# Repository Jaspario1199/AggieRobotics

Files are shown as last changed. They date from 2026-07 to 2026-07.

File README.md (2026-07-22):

# VEX Tri-Ball Belt Accelerator 🎯

A single VEX mechanism that **pushes, launches, pulls, and holds** a tri-ball —
a **belt accelerator** ("belt railgun"). The ball runs down a barrel gripped
between two motor-driven **conveyor belts** on its left and right (the "rails"),
with **top + bottom decks** containing it and forming the floor it rides on. Like
a railgun it accelerates the ball *along* the barrel — but the rails are traction
belts, and belt **surface speed** is the exit speed. One drive replaces an intake
**and** a puncher **and** a pusher: fewer subsystems, less weight, faster cycles.

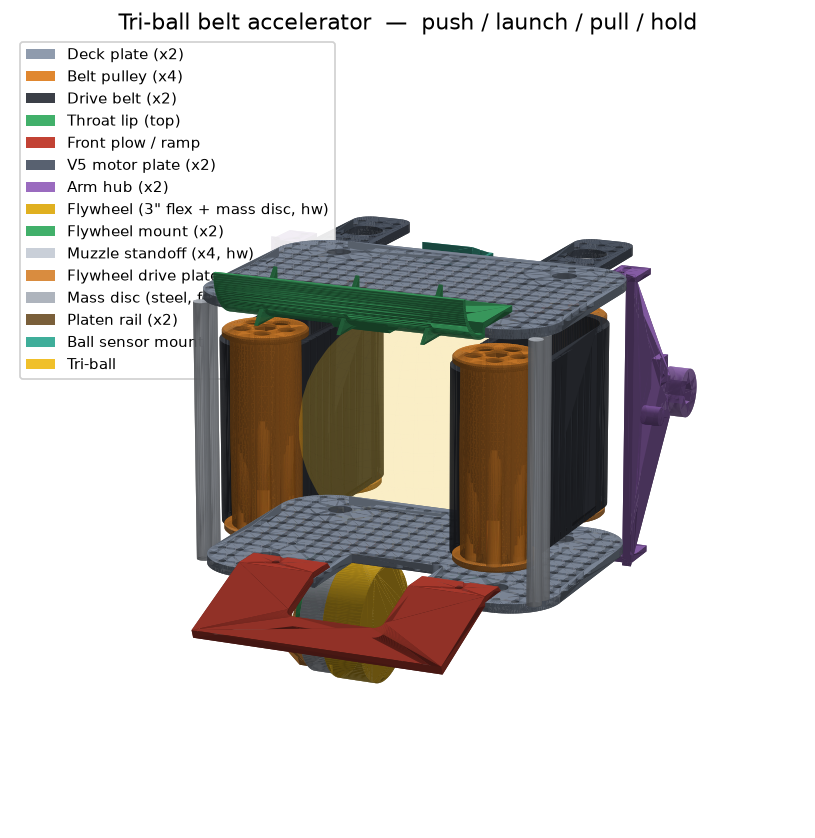
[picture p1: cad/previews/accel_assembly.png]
Tri-ball belt accelerator


## The four modes

| Mode | The belts… | …and the ball |
|---|---|---|
| **PULL** (intake) | run inward, **slow** | friction draws the tri-ball into the barrel |
| **HOLD** (control) | **stopped** | pinched between the belts (compression grip) |
| **LAUNCH** | run outward, **fast** | spun up to belt speed and fired out the muzzle |
| **PUSH** | **off** | drive forward — the front plow shoves it through a contested zone |

Because exit speed ≈ belt surface speed, you set a belt *speed* (not a launch
impulse) and the barrel length does the accelerating — so near/far shots are
repeatable.

## Design basis (first principles)

Sized from four relations, all parametric in [`cad/params.py`](cad/params.py):

| Quantity | Relation | Set by |
|---|---|---|
| Exit speed (no slip) | `v_exit ≈ v_belt = (RPM/60)·π·PULLEY_PITCH_DIA` | pulley Ø + motor RPM (gear-up) |
| Grip (no slip) | `μ·N ≥ m_ball·a` | `BALL_COMPRESSION` (normal force) |
| Channel gap | `BELT_GAP = TRIBALL_DIA − 2·BALL_COMPRESSION` | ball size + squeeze |
| Barrel length | accel distance to reach `v_belt` | `BARREL_LEN` |

Pick `PULLEY_PITCH_DIA` and motor RPM for the exit speed you want,
`BALL_COMPRESSION` for enough grip that the ball doesn't slip, and `BARREL_LEN`
long enough that the ball leaves at (near) belt speed. The side **belts squeeze**
the ball (`BELT_GAP < TRIBALL_DIA`) for grip, while the **top + bottom decks** sit
a hair wider than it (`2·SIDE_INNER_HALF > TRIBALL_DIA`) so it's captured but not
crushed and can't pop out top or bottom.

## Parts

Every part is a **parametric CadQuery script** that exports genuine **STEP**
(Fusion 360 / SolidWorks / FreeCAD / Onshape) and **STL** (ready to slice). The
generated files are committed, so you can open/print without installing anything.

| Part | What it is | Print | Material |
|---|---|---|---|
| [`belt_pulley`](cad/parts/belt_pulley.py) | Flanged traction pulley, ½" hex bore, lightened | ×4 | PLA/PETG |
| [`drive_belt`](cad/parts/drive_belt.py) | The traction loop the ball rides on — 6 mm thick so the 4 mm squeeze stays inside the belt (rigid ball) | ×2 | TPU 95A (printed — VEXU-legal fabricated part) |
| [`accel_plate`](cad/parts/accel_plate.py) | Grid-perforated deck (top + bottom); 4 vertical pulley bores (rear = tension slots); **flip-symmetric** | ×2 | PLA/PETG |
| [`throat_lip`](cad/parts/throat_lip.py) | Flared TOP mouth guide — bolts to the deck grid, zero aperture intrusion | ×1 | PLA/PETG |
| [`front_plow`](cad/parts/front_plow.py) | Bottom ramp + push blade + bottom mouth guide in one part (chamfered — no step in the ball path) | ×1 | PLA/PETG |
| [`motor_plate`](cad/parts/motor_plate.py) | V5 Smart Motor mount, geared up to a drive-pulley shaft (1.5" centre distance) | ×2 | PLA/PETG |

## Built to the VEX system

- **½" high-strength hex** bores on every pulley (`VEX_HEX_AF`); lock them on with
  shaft collars or the set-screw access hole.
- The **0.5" (12.7 mm) hole grid** fills each deck, so bearing flats, the throat
  lips, the plow, the V5 motors, and the drivetrain C-channel all bolt anywhere.
  The **rear pulley bores are tension slots** — slide the idlers back to tension
  each belt. Holes are **#8-32** clearance (`VEX_HOLE`).
- Sized for the VEX Over-Under **tri-ball** via `TRIBALL_DIA`. Tune
  `PULLEY_PITCH_DIA`, `BARREL_LEN`, `BELT_WIDTH`, `BALL_COMPRESSION`, and
  `SIDE_INNER_HALF` and re-run the export to fit a different element.

> The printed parts are the *custom* geometry (decks, pulleys, throat lips, plow).
> The motors, ½" hex shafts, bearing flats, gears, shaft collars, and the belts
> themselves are stock VEX / COTS — don't print those (print the belts in TPU
> only if you can't source a loop).

## Assembly

1. Snap a VEX **bearing flat** over each of the four pulley bores in each deck
   (front pair fixed; rear pair in the **tension slots**).
2. Stand a **belt pulley** on a **vertical ½" hex shaft** at each corner of the
   barrel — a front + rear pair on the left, a front + rear pair on the right —
   running between the top and bottom decks. Lock with shaft collars / set screws.
3. Loop a **drive belt** around each side's pulley pair (one belt left, one right);
   slide the rear idlers back in their slots to tension.
4. Bolt a **motor plate** on for each belt and gear the **V5 motor** up to that
   side's rear drive pulley (e.g. 12T→36T) for launch belt speed.
5. Bolt the two **throat lips** across the muzzle grid holes — one top, one bottom —
   to flare the mouth.
6. Bolt the **front plow** across the muzzle-floor grid holes — it also ties the two
   decks into a rigid frame.
7. Bolt the whole frame to your drivetrain C-channel through the grid.

## Regenerate the CAD

Edit [`cad/params.py`](cad/params.py), then:

```bash
pip install -r requirements.txt
python -m cad.export_all      # writes cad/{step,stl,previews}
```

## Print settings

- **Structural parts** (decks, pulleys, throat lips, plow): **PETG**, 0.2 mm
  layers, **4 walls**, **40–50 % infill** — these take load and impact.
- **Belts** (only if you can't source a loop): **TPU 95A**, so they flex around
  the pulleys.
- Most parts print support-free in the orientation described in each script's
  docstring. The throat lips overhang mildly — a couple of supports or a
  split-print are fine.

## Layout

```
cad/
  params.py         # ← edit YOUR dimensions here (ball size, belt/pulley sizing)
  parts/*.py        # one parametric script per part
  export_all.py     # regenerate everything + the assembly preview
  lib.py            # STEP/STL export + PNG preview helper
  vexlib.py         # 1/2" hex bore + 0.5" VEX hole-grid helpers
  step/  stl/  previews/   # generated output (committed)
```

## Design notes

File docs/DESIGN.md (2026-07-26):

# VEXU Over Under Robot — Design Document (working draft)

> **Process note.** No CAD until this document has been critiqued and iterated to
> "no holes." This is the single source of truth for *what every part is, why it
> exists, how it interacts with everything else, and how it is fastened.* Sections
> tagged **[RULES — pending]** are being grounded against the official VEXU Over
> Under manual (research in progress) and will be filled with cited numbers before
> we lock v1.

---

## 0. Locked decisions (from the user)

| # | Decision | Choice | Why it matters downstream |
|---|---|---|---|
| D1 | Drivetrain | **X-drive** (4 omni @ 45°) | Sets corner geometry, motor count (4), center-of-mass, and how the arm mass loads the base. |
| D2 | Starting envelope | **~15 in cube** (VEXU small-robot class; exact limit pending) | Everything must nest inside this at match start; the arm expands *after* start. |
| D3 | Actuation | **Hybrid** — motors for drive + belts, pneumatics for arm deploy/latch | Trades motor budget for air; sets solenoid/reservoir count. |
| D4 | Arm | **Linear slide + pivot** (telescoping extend, then fold to the back) | Two clean DOF; defines the shoulder joint, the slide, and the folded/deployed poses. |

---

## 1. Purpose & the core idea

Rebuild (and improve) a VEXU Over Under robot whose entire manipulator is **one
belt accelerator** (the "belt railgun" in this repo) mounted on a **fold-out
arm**, on a **holonomic X-drive** base.

The one manipulator does four things (see the mechanism README):

- **PULL** (intake) — belts run inward, draw the tri-ball into the barrel.
- **HOLD** — belts stop, ball pinched between them (ball control while driving).
- **PUSH** — belts off, drive forward, the plow shoves the ball.
- **LAUNCH** — belts spin up, ball fired out at belt surface speed.

**The dual-position trick.** The belt barrel is open at both ends and the belts
are reversible, so a *single* working mouth can both intake and launch. The arm
gives that mouth two useful home positions:

- **Deployed (extended forward):** the arm slides + swings the belt head out the
  **front** of the robot, mouth facing forward — intake off the field, or launch
  forward.
- **Folded (resting on the back):** the arm folds ~180° so the belt head lies on
  the rear deck with its mouth now facing **rearward** — intake/launch off the
  *back* of the robot without deploying the arm.

So the robot can work off either end depending on what the match wants, and the
**folded pose is also the legal start configuration** (compact, inside the cube);
**deploying = the post-start expansion** the rules allow.

---

## 2. Requirements

### 2.1 Rules/legality (VEXU / VURC 2023–24 Over Under)
Grounded against the VRC Over Under Game Manual v4.0 + VEX U appendix and the
VURC Q&A. Numbers are high-confidence unless flagged **(verify)**; the five
flagged items in §11-H9 must be checked against the manual PDF before the build.

- **R1 Two robots/team, two size classes.** Start cubes are **24×24×24 in** and
  **15×15×15 in**. *We are building the **15″ robot.*** It must start fully inside
  the 15″ cube and pass inspection there.
- **R2 Expansion after start (corrected — good news).** The **15″ robot is governed
  by standard SG2/SG3 → it may expand horizontally to 36 in**; only the *start* is
  the 15″ cube. The **24 in** cap (VUG2) applies to the team's *other* (24″) robot,
  not this one. → The arm's ~20.5″ deployed footprint is legal with large margin;
  reach is not the binding constraint (packaging/tipping are).
- **R3 Motors: no count cap in VEXU** (VRC's 88 W cap is removed). BUT VEXos
  drops the per-motor current limit once **>8 motors** are connected. → **Hold the
  total to ≤ 8 V5 motors** so each keeps full current (matters for launch power).
- **R4 Pneumatics (corrected):** **VEX pneumatics only**, **≤2 reservoirs**,
  **100 psi max**, VEX solenoids. (Not "less restricted" — the 2-reservoir limit
  binds.) **Air budget matters:** a 200 mL reservoir ≈ 15–25 double-acting actuations
  → don't cycle the slide every intake or it runs dry; compute the budget or move the
  slide to the spare motor.
- **R5 Parts (corrected to VEX U appendix, not VRC):** **3D-printed + custom-fabricated
  parts from the raw-material list are legal and unlimited** — **polyurethane is on the
  list, so TPU belts are legal as a fabricated part** (not "because COTS belts are
  banned"). **COTS bearings + linear slides/bearings are legal** (ruled "fasteners,"
  Q&A #1208). **COTS gears are NOT legal** (VUR4 — must be VEX or fabricated). **Only
  V5 Smart Motors** may actuate (no other motors/servos). **1 V5 Brain + 1 radio** per
  robot; **1 extra battery allowed for sensors/processing only** (not motors/solenoids).
  → Keep gears + motors + wheels VEX; the linear slide *may* be COTS but keeping it VEX
  is the safe call; print structure/pulleys/plates + TPU belts freely.
- **R6 No robot weight limit.** (Still keep mass sane for tipping/agility.)
- **R7 Two-robot team.** VEX U fields **two robots (24″ + 15″)**; the standard split is
  **big robot elevates, small robot scores.** *This* is the 15″ scorer → deferring hang
  (H11) is justified **iff** the 24″ partner elevates. Elevation scores **20/15/10/5**
  (confirmed); measured under the robot's lowest point (bar height: verify Appendix A).

**Field/scoring targets for the launcher (designer-usable):**
- Field **12 ft × 12 ft**; central **Barrier** ≈ **2.9 in** tall PVC — you launch
  *over* it. Each half ~72 in deep.
- **Two netted goals**, lowest opening ≈ **5.78 in** above the tiles; a triball
  scores when **≥2 of its 3 points are inside** = **5 pts** (offensive zone = 2).
- Launching over the barrier is **legal and mainstream**. Typical cross-barrier
  shot ≈ **4–8 ft** horizontal clearing a ~3 in barrier → **modest launch energy**
  (this shrinks the belt head we need). Never launch elements *out of* the field.

### 2.2 Functional
- F1 Intake a tri-ball off the floor (front, deployed).
- F2 Intake a tri-ball off the floor (rear, folded) — the "resting on the back" mode.
- F3 Hold a ball securely while driving holonomically (no ejection on hard turns).
- F4 Launch a ball across the field into the far goal (repeatable near/far).
- F5 Push a ball through a contested zone (belts off, plow engaged).
- F6 Deploy/retract the arm reliably and hold either pose under drive loads.
- F7 Drive omnidirectionally (translate + rotate simultaneously).

### 2.3 Mechanical / quality
- M1 Fit the start envelope with margin (target ≥ 0.5 in on each axis).
- M2 Center of mass low and centered enough that the deployed arm doesn't tip it.
- M3 Every load path resolved into metal fasteners into metal or heat-set inserts;
  no printed part carries a thread that sees repeated high load.
- M4 Field-serviceable: swap a belt, motor, or the whole arm head without a teardown.
- M5 Wire/air routing that survives the arm's full range of motion (no pinch/stretch).

---

## 3. System architecture

Six subsystems. Each has its own spec below; §7 is the interaction matrix and §8
the fastening scheme.

```
                         ┌─────────────────────────────┐
                         │  S6 Power & Electronics       │
                         │  (V5 brain, battery, radio)   │
                         └──────────────┬────────────────┘
             commands / power           │
        ┌───────────────┬───────────────┼───────────────┬──────────────┐
        ▼               ▼               ▼               ▼              ▼
  ┌───────────┐  ┌────────────┐  ┌────────────┐  ┌────────────┐ ┌────────────┐
  │ S2 X-drive │  │ S3 Belt    │  │ S4 Arm     │  │ S5 Pneu-   │ │ S1 Chassis │
  │ (4 motors) │  │ head       │  │ deploy     │  │ matics     │ │ / structure│
  │            │  │ (2 motors) │  │ (slide+piv)│  │ (air)      │ │ (frame)    │
  └─────┬──────┘  └─────┬──────┘  └─────┬──────┘  └─────┬──────┘ └─────┬──────┘
        │ reacts thrust  │ carries ball  │ moves head    │ actuates     │ carries
        └────────────────┴───────┬───────┴──────┬────────┘   slide/latch │ everything
                                  ▼              ▼                        ▼
                          the tri-ball    the field                 the cube envelope
```

- **S1 Chassis / structure** — the frame everything bolts to; two decks.
- **S2 X-drive** — 4 omni wheels @45°, 4 V5 motors; holonomic base.
- **S3 Belt head** — the belt accelerator (this repo's parts), 2 belt motors.
- **S4 Arm deploy** — shoulder pivot + linear slide that carry S3 between poses.
- **S5 Pneumatics** — reservoir(s), solenoids, cylinders for slide/latch.
- **S6 Power & electronics** — V5 brain, battery, radio, wiring, air valves.

---

## 4. Packaging & coordinate strategy

**World frame (robot):** +X = right, +Y = forward, +Z = up. Origin at the base
center on the floor plane.

**Two decks:**
- **Lower deck (drive deck):** X-drive motors + wheels, V5 battery, brain, and the
  air reservoir — the heavy stuff, low, for a low CoM.
- **Upper deck (arm deck):** the shoulder pivot, the linear slide rails, and the
  folded belt head resting surface. The belt head sits *here* when folded.

**Start (folded) config → fits the cube.** Belt head folded flat on the upper
deck, mouth facing rear, arm slide retracted, pivot latched. This is the ≤15″
start box.

**Deployed config → the legal expansion.** Slide extends forward, pivot swings the
head down/out to intake height at the front. The head clears the front drive
wheels because the X-drive corners are chamfered inward (§S2).

**The central packaging tension (must be solved before CAD):** the belt head is
inherently ~tri-ball-sized (the barrel wraps a ~7″ ball). A head that big folded
on a 15″ deck plus a 15″ X-drive base plus electronics is tight. Candidate
resolutions, to be decided in §11:
- (a) **Compact the head** to a *single* belt-gap barrel just long enough to grip
  the ball over ~1 wrap (shorten `BARREL_LEN`, drop to the minimum pulley count),
  accepting lower launch energy for size.
- (b) **Cantilever the head off the back** in the folded pose so it overhangs the
  rear bumper *within* the expansion allowance rather than the start cube — i.e.
  the head only has to be inside the cube if we call folded the "start," so we may
  instead start with the head nested lower and deploy both directions.
- (c) **Split decks vertically** — head folds into the volume *above* the drive
  motors, using full cube height (Z) rather than deck area (XY).

---

## 5. Subsystem specs

### S1 — Chassis / structure
**Purpose:** rigid frame that (a) locates the 4 X-drive corners, (b) carries the
two decks, (c) provides the shoulder-pivot mounts and slide-rail mounts, (d) takes
launch reaction and drive thrust into the wheels without racking.

**Build:** VEX aluminum C-channel perimeter (square), corner gussets, standoffs
between decks. Custom 3D-printed brackets only where they *locate* parts, not where
they carry the primary launch load (that goes through C-channel + steel screws).

**Key interfaces:**
- 4× corner motor/wheel modules (S2) bolt to the lower-deck corners at 45°.
- Shoulder-pivot bearing blocks (S4) bolt to the upper deck, rear edge.
- Slide rails (S4) bolt along the upper deck.
- Battery/brain/reservoir trays (S6/S5) strap to the lower deck.

**Fastening:** C-channel joined with 8-32 screws + nylocks through the 0.5″ grid;
printed brackets use heat-set inserts *only* for light locating loads; primary
load joints are metal-to-metal.

### S2 — X-drive (holonomic)
**Purpose:** omnidirectional translation + rotation; also *reacts the launch
recoil* and any push loads.

**Build:** 4× VEX 4″ omni wheels at the four corners, each wheel's roller axis at
45° to the frame, each driven by 1× V5 Smart Motor through a spur pair (ratio TBD
for a speed/torque target; start ~ direct or 1:1.6 for speed). Wheels ride on ½″
hex axles in bearing flats.

**Why X-drive (recap):** compact center (leaves the middle free for the arm mass
and battery), true holonomic, and the 45° wheels keep the corners — where the
front wheels would otherwise block the deployed head — clear.

**Motors:** 4 (one per corner). **[RULES — pending]** confirm this fits the budget
alongside S3's belt motors and S4.

**Interactions:** must *hold position* during launch (recoil pushes the base
backward); driver or code applies a brief brace (all wheels resist) at launch, or
we launch only while translating to cancel recoil. Flagged as a control item (§6).

### S3 — Belt head (the manipulator)
**Purpose:** the four-mode manipulator (pull/hold/push/launch). This is the belt
accelerator already modeled in this repo (`cad/parts/*`): 4 `belt_pulley`, 2
`drive_belt`, 2 `accel_plate` decks, 2 `throat_lip`, 1 `front_plow`.

**Tri-ball reality (corrects the mechanism's current sizing):** the ball is a
**three-lobed shape ≈ 6.18 in tip-to-tip**, body ≈ 4–4.5 in across, ≈ **138 g**,
hollow plastic — *not* a 178 mm sphere. Two consequences:
- The **throat opening** must admit the ~6.18 in tip dimension in any orientation
  (the ball is irregular, so intake orientation matters), while the **belts grip
  the ~4–4.5 in body**. So: wide throat, narrower belt gap. `TRIBALL_DIA` in
  `params.py` becomes the *tip* size for the throat; a new `BALL_BODY` (~110 mm)
  sets `BELT_GAP`. → **[H10]**.
- Everything shrinks vs. the current model — good for §4 packaging (H1).

**Adaptation for the arm:**
- `BARREL_LEN`, `BELT_WIDTH`, and pulley Ø are the levers to size the head to the
  corrected ball and the folded envelope (§4, §11).
- **Belts are 3D-printed TPU** (legal custom part per R5) — not a COTS belt. Tread
  wraps the ~4–4.5 in body for grip.
- **Reversible + dual-end:** belts driven by 2 V5 motors (one per side) for
  independent spin control and launch power; the barrel's single mouth intakes or
  launches by belt direction/speed, and the fold reorients that mouth front↔rear.
- **Launch energy is modest** (R2 target ~4–8 ft over a ~3 in barrier, 138 g ball),
  so the head need not be large — belt surface speed + a good exit angle dominate.
- Mounts to the arm's moving carriage (S4) via the belt-head decks' grid holes.

**Motors:** 2 (belt L, belt R). Could be reduced to 1 with a cross-linkage if the
motor budget is tight — noted as a trade in §11.

**Interactions:** hands the ball to "the field" on launch; receives it from the
floor on intake; its mass is the biggest thing the arm (S4) has to move and the
base (S2) has to keep from tipping.

### S4 — Arm deploy (linear slide + pivot)
**Purpose:** carry the belt head (S3) between **folded** (rear deck, mouth rear)
and **deployed** (front, mouth forward, at intake height), and hold either pose
under load.

**Two DOF:**
1. **Shoulder pivot** — a hinge at the rear-top of the upper deck. Swings the arm
   ~180° from lying-on-the-back to pointing-forward-down. **Actuation candidate:**
   a V5 motor through a high-reduction gearbox (holds position, precise angle) —
   *or* pneumatic via a linkage if we can hit the throw (decision in §11; motor
   is the current lean because 180° under a heavy head wants controlled, holdable
   motion).
2. **Linear slide** — a telescoping rail on the arm that extends the head forward
   for reach when deployed. **Actuation:** pneumatic cylinder (fast, self-holds at
   both stroke ends), matching D3 (pneumatics for deploy).

**Latch:** a pneumatic (or passive over-center) latch holds the **folded** pose for
the start and during hard driving so the head can't flop; released to deploy.

**Interactions:** the pivot axis, slide stroke, and folded rest surface are the
geometry that S1 must provide and that S3's size must fit; the air lines and the 2
belt-motor cables must survive the full travel (S5/S6 routing).

### S5 — Pneumatics
**Purpose:** actuate the linear slide (extend/retract) and the fold latch; possibly
a launch-hood/angle flip. **[RULES — pending]** confirm reservoir/cylinder count.

**Build (candidate):** 1–2 air reservoirs on the lower deck, a regulator, and
2–3 double-acting cylinders (slide, latch, optional hood) driven by V5 pneumatic
solenoid valves off the brain's 3-wire ports.

**Interactions:** valves commanded by S6; cylinders act on S4; reservoir mass sits
low in S1 for CoM.

### S6 — Power & electronics
**Purpose:** power and command everything.
**Build:** 1× V5 Brain, 1× V5 Battery, 1× V5 Radio + controller, motor cables,
3-wire leads to pneumatic solenoids, and (optional) sensors: an optical/distance
sensor at the mouth (ball present?), an IMU for field-oriented holonomic drive, and
motor encoders (built into V5) for belt-speed = launch-speed closed loop.
**Interactions:** every subsystem; wire routing across the arm hinge is a named
risk (M5). **[RULES — pending]** total motor count must fit the VEXU limit.

---

## 6. Control strategy (per mode)

| Mode | Drive (S2) | Belts (S3) | Arm (S4) | Pneu (S5) | Notes |
|---|---|---|---|---|---|
| Drive/seek | holonomic | off or HOLD | folded or deployed | latched | field-oriented via IMU |
| Intake front | creep fwd | PULL (inward, slow) | deployed, mouth fwd | slide out | ball sensor confirms capture → HOLD |
| Intake rear | creep back | PULL | folded, mouth rear | latched | no deploy needed |
| Hold + travel | holonomic | HOLD (stall/creep) | either | — | belts lightly grip; no launch energy |
| Push | drive into ball | off | deployed low | slide out | plow engaged |
| Launch | brace/translate to cancel recoil | spin up to target belt speed | pose set for angle | hood set | encoder closes speed loop for range |

**Recoil:** launching a ~60 g ball at speed imparts a recoil impulse; the X-drive
holds/opposes it (all four wheels brace), or we launch while creeping to cancel —
a control-level item, but it validates choosing a holonomic base that can hold
station.

---

## 7. Interaction matrix (who touches whom, and how)

| ↓ acts on → | S1 Chassis | S2 Drive | S3 Belt head | S4 Arm | S5 Pneu | S6 Elec |
|---|---|---|---|---|---|---|
| **S1 Chassis** | — | locates 4 corners; takes thrust | provides folded rest surface | provides pivot + rail mounts | holds reservoir tray | holds brain/battery trays |
| **S2 Drive** | thrust/recoil into frame | — | keeps base under the ball | keeps base stable while arm moves | — | draws power/PWM |
| **S3 Belt head** | mass on upper deck | ball control aids pushing | — | is the payload the arm carries | — | 2 motor cables |
| **S4 Arm** | loads pivot/rails | shifts CoM when deployed | positions + orients the mouth | — | driven by slide cylinder + latch | motor cable + encoder |
| **S5 Pneu** | reservoir mass | — | — | extends slide, throws latch | — | solenoids on 3-wire ports |
| **S6 Elec** | tray loads | commands drive | commands belts + reads ball sensor | commands pivot + reads angle | commands valves | — |

*(Each non-empty cell is a real interface that must have a defined mount, load
path, and — where it moves — a routing plan. Cells that move relative to each other
across the hinge: S3↔S6 cables and S4↔S5 air lines — flagged M5.)*

---

## 8. Fastening scheme (global rules)

1. **Primary structure (frame, decks, motor mounts, shoulder blocks):** VEX metal
   C-channel/plate, joined with **8-32 screws + nylock nuts** through the 0.5″ grid.
   No printed part in a primary load path.
2. **Shafts:** ½″ hex in VEX bearing flats; wheels/pulleys/gears retained with
   **shaft collars + set screws**; hex captures torque.
3. **Printed parts (belt head decks, pulleys, throat lips, plow, brackets):**
   bolt to metal with 8-32 clearance holes + nuts; where a screw must thread into
   plastic, use a **heat-set brass insert**, never a bare tapped hole under load.
4. **Belt-head to arm carriage:** the two accel-plate decks bolt to the carriage
   through their existing 0.5″ grid, straddling the pulley bores for a stiff joint.
5. **Pivot joint:** hardened ½″ or ¾″ shaft in dual bearing blocks (both sides),
   never a single-shear printed pivot.
6. **Air/electrical:** service loops at the hinge; strain-relief clamps on both the
   fixed and moving sides so nothing pulls on a connector.

---

## 9. Mass / CG budget (rough, to refine)

| Group | Est. mass | Location | CoM effect |
|---|---|---|---|
| X-drive (motors+wheels+frame) | heavy | low, corners | anchors CoM low/centered |
| Battery + brain + reservoir | heavy | low deck, centered | low CoM |
| Belt head + 2 motors | heavy | upper/rear (folded) or front (deployed) | **the swing risk** |
| Arm slide + pivot gearbox | medium | upper rear | rear-biases CoM |

**The tipping check (must pass in §10 iteration):** with the arm fully deployed
forward + a ball at the mouth, the CoM must stay inside the front wheelbase with
margin. Levers: keep battery/reservoir low and rearward to counterbalance; limit
slide extension; widen the effective front track via the 45° wheel geometry.

---

## 10. BOM (skeleton — quantities/motors finalize after [RULES])

| Subsys | Item | Qty | Purpose |
|---|---|-----|---|
| S1 | VEX aluminum C-channel (various) | TBD | frame perimeter + decks |
| S1 | Corner gussets / plates | TBD | rack-resist the frame |
| S1 | Standoffs (deck spacers) | TBD | separate the two decks |
| S2 | VEX 4″ omni wheel | 4 | X-drive |
| S2 | V5 Smart Motor (11W) | 4 | drive |
| S2 | ½″ hex axle + bearing flats + collars | 4 sets | wheel mounts |
| S2 | Spur gear pair | 4 | drive ratio |
| S3 | `belt_pulley` (printed) | 4 | belts ride on these |
| S3 | `drive_belt` (**3D-printed TPU** — legal custom part) | 2 | grip + accelerate the ball |
| S3 | `accel_plate` deck (printed) | 2 | barrel walls / pulley mounts |
| S3 | `throat_lip` (printed) | 2 | flared mouth |
| S3 | `front_plow` (printed) | 1 | push mode + cross-brace |
| S3 | V5 Smart Motor | 2 | belt drive (or 1 + cross-link) |
| S3 | ½″ hex shafts + bearings + collars | 4 | pulley shafts |
| S4 | Linear slide rail + carriage | 1 | extend the head |
| S4 | Pneumatic cylinder (slide) | 1 | extend/retract |
| S4 | Shoulder pivot shaft + bearing blocks | 1 set | fold DOF |
| S4 | V5 Smart Motor + gearbox (pivot) | 1 | fold actuation (candidate) |
| S4 | Latch (pneumatic or over-center) | 1 | hold folded |
| S5 | Air reservoir | 1–2 | pneumatic supply |
| S5 | Solenoid valve | 2–3 | slide/latch/hood |
| S5 | Regulator + tubing + fittings | 1 set | plumbing |
| S6 | V5 Brain | 1 | controller |
| S6 | V5 Battery | 1 | power |
| S6 | V5 Radio + Controller | 1 | comms |
| S6 | Optical/distance sensor | 1 | ball-present at mouth |
| S6 | IMU (or V5 built-in) | 1 | field-oriented drive |

**Motor tally:** 4 drive + 2 belt + 1 pivot = **7 V5 motors** (slide + latch are
pneumatic). VEXU has no motor cap, but we deliberately stay **≤8** so VEXos keeps
each motor at full current (launch power). 1 spare port; use it for an assist
roller, a 2nd pivot motor, or leave it. All motors + wheels + gears + bearings +
shafts are **VEX** (R5); pulleys/plates/lips/plow are **printed**, belts **TPU**.

---

## 11. Open holes to close *before* CAD (the iteration list)

These are the "holes" we critique and drive to zero. Each must get a decided
answer written back into the sections above.

- **H1 Size reconciliation** *(the #1 hole; eased by H10)* — does the belt head fit
  folded in the 15″ cube with the X-drive + electronics? With the corrected smaller
  ball the head shrinks a lot; still must pick the packaging (§4 a/b/c) and prove
  the folded stack ≤ 15″ on all axes with ≥0.5″ margin, and the deployed footprint
  ≤ the R2 horizontal cap.
- **H2 Fold actuation** — motor vs pneumatic-linkage for the ~180° pivot; confirm it
  holds the head folded and deployed under drive/recoil. (Motor is the lean.)
- **H3 Motor budget** — *mostly resolved:* VEXU has no cap but we hold **≤8** to keep
  full current. Plan = 4 drive + 2 belt + 1 pivot = **7** (1 spare). Decide 1-vs-2
  belt motors only if we want the 8th for an assist roller or 2nd pivot motor.
- **H4 Recoil management** — quantify launch recoil (≈ m·Δv of a 138 g ball) vs base
  holding force; confirm the X-drive holds station, or launch-while-creeping.
- **H5 Tipping** — CoM/wheelbase check deployed + loaded (§9).
- **H6 Dual-end geometry** — verify the *same* mouth presents correctly both folded
  (rear) and deployed (front); define the two intake heights (front floor pickup;
  rear pickup height when folded). Throat must clear the 6.18″ tip in any orientation.
- **H7 Wire/air over the hinge** — define the service-loop routing (M5).
- **H8 Launch performance** — *targets now known:* clear a ~2.9″ barrier into a goal
  whose opening is ~5.78″ up, ~4–8 ft away, 138 g ball. Solve exit speed → belt
  surface speed = `(RPM/60)·π·PULLEY_PITCH_DIA` → motor RPM + gear-up; set a launch
  angle (hood). Modest energy → confirms a small head is enough.
- **H9 Rules legality** — *filled (§2.1).* Residual items to verify against the
  manual PDF: (1) 15″-robot horizontal expansion cap; (2) elevation-bar height +
  point values; (3) exact VUR rule IDs; (4) triball weight/secondary dims; (5) VEXU
  reservoir-count nuance / 2nd brain-battery allowance.
- **H10 Ball re-size** — update `params.py`: `TRIBALL_DIA` → ~6.18″ *tip* (throat),
  add `BALL_BODY` ~110 mm → `BELT_GAP`; re-derive head size. Feeds H1/H6/H8.
- **H11 Endgame hang (optional / stretch)** — elevation scores 20/15/10/5. Could the
  folding arm double as a hook to hang on the Elevation Bar? Big value if cheap;
  out of core scope for v1 but worth a hook geometry check before we finalize the arm.

---

## 13. Resolved design — closing H1–H11 (v0.3)

Concrete decisions + numbers that supersede the placeholders above. Units mixed
(VEX is imperial; mechanism is metric) but each value notes both where it matters.
Masses/dims marked ≈ are engineering estimates to confirm in CAD.

### 13.0 Tri-ball working numbers (H10 — closed)
- Tip-to-tip **157 mm (6.18″)** → sets throat + tip-clearance.
- Body across **≈110 mm (≈4.3″)** → sets the belt grip *(community-approx; verify)*.
- Mass **138 g**, **rigid hollow shell** → grip by **compliant TPU belts** (belts
  deform, ball doesn't). `params.py`: `TRIBALL_DIA`=157 (throat), new `BALL_BODY`=110.

### 13.1 Chassis (S1) — closed
- Footprint **368 × 368 mm (14.5″)** inside the 15″ cube (≈0.5″/side margin, M1).
- Drive deck height **≈100 mm (4″)**; upper/arm deck above it.
- VEX aluminum C-channel perimeter + corner gussets; steel 8-32 through the 0.5″ grid.

### 13.2 X-drive (S2) — closed
- 4× VEX **3.25″ omni** at 45° corners, **½″ hex** in bearing flats, **shaft-collar**
  retained. Each on **1× V5 motor, 600 RPM (blue) cartridge, ~1:1** → **≈8 ft/s** free.
- Holonomic control + **field-oriented via a V5 Inertial (IMU)**.
- **Recoil (H4 — closed):** launch impulse = m·v = 0.138 kg × 6 m/s ≈ **0.83 kg·m/s**;
  over a ~0.06 s contact ≈ **~14 N** peak. Wheel friction (robot ≈5 kg → ~25 N/wheel
  static) dwarfs it → base holds station; **no special recoil measure needed**, and
  code adds a 4-wheel brace at launch for repeatability.

### 13.3 Belt head (S3) — compact, closed (H1)
- `BELT_GAP` **≈100 mm** (grips the ≈110 mm body via TPU deform).
- Tip clearance (deck spacing across the other axis) **≈170 mm** so the 157 mm tips
  clear as the ball tumbles in.
- `BARREL_LEN` **≈90 mm**, `BELT_WIDTH` **≈90 mm**, `PULLEY_PITCH_DIA` **50 mm**.
- Throat lips flare the mouth to **≈160 mm** to swallow the tip in any orientation;
  the throat **cams the ball into a repeatable lobe-leading pose** for consistent
  launch (H6 detail; confirm against real ball CAD).
- **Head envelope ≈ 180 × 165 × 150 mm (≈7 × 6.5 × 6″)** — about half the robot.
- **2× V5 belt motors** geared **≈3.75:1** (600 RPM → ~2250 RPM at the 50 mm pulley).
- **Launch (H8 — closed):** belt surface speed v=(RPM/60)·π·D = (2250/60)·π·0.05 ≈
  **5.9 m/s**. Projectile range R=v²·sin2θ/g: at 45°, v=4.9 m/s→**2.4 m (8 ft)**;
  v=3.5→1.25 m (near). So **~3.5–6 m/s covers the whole ~4–8 ft window**; clears the
  74 mm barrier and reaches the ~147 mm goal opening. Speed set by encoder-closed
  belt RPM; a **launch hood sets ~40–45°**. Modest energy → the compact head suffices.

### 13.4 Arm (S4) — closed (H1/H2/H6)
- **Fold plane is vertical (fore-aft).** The shoulder pivot swings the head between
  **front-floor** (deployed intake/launch) and **rear working** (folded intake/launch
  off the back), passing over the top. ~**180°** throw.
- **Pivot = V5 motor + ≈7:1 reduction** (H2 — closed). Hold torque worst case
  (head ≈1.5 kg at ≈0.2 m, horizontal) = m·g·r ≈ **2.9 N·m**; motor+7:1 gives
  ample margin and 180° in ~1.5 s; **active braking holds deployed**, and a
  **pneumatic latch** holds folded (start + hard driving).
- **Slide = VEX linear rail + pneumatic cylinder, stroke ≈100 mm (4″)** for front reach.
- **Deployed footprint:** base 14.5″ + reach ≈6″ ≈ **20.5″ < 24″** expansion target (R2).
- **Poses / intake heights (H6 — closed):**
  - *Start/folded:* head at rear, mouth angled **down-rear ~30–45°** to work off the
    floor behind; slide retracted; latched. Stack height ≈ **280 mm (11″) < 15″** (M1).
  - *Deployed-front:* mouth at floor (**0–50 mm**), slide out.

### 13.5 Pneumatics (S5) — closed
- **1 air reservoir**, regulator at **~60–80 psi** (100 psi max, R4), on the low deck.
- **2 double-acting cylinders:** slide (≈100 mm stroke) + fold latch — each on a V5
  **3-wire solenoid**. (Reserve capacity for an optional hood cylinder.)

### 13.6 Power/electronics (S6) — closed
- **7 V5 motors** (4 drive, 2 belt, 1 pivot) — ≤8 for full current (R3). **1 spare port.**
- V5 Brain, Battery, Radio + Controller; **Inertial sensor** (field-oriented drive);
  **1 distance/optical sensor** at the mouth (ball-present → auto HOLD); motor encoders
  close the belt-speed loop for launch range.
- **Routing (H7 — closed):** the 2 belt-motor cables + pivot encoder + the slide air
  line cross the shoulder **coaxially with the pivot axis** with a service loop,
  strain-relieved on both fixed and moving sides (M5). Reservoir/valves on the low deck.

### 13.7 Tipping (H5 — closed)
- Deployed + ball: head ≈1.5 kg at ≈0.25 m ahead of pivot → CoM shift ≈ 1.5·0.25/5.0
  ≈ **75 mm** forward; front half-wheelbase ≈ **184 mm** → **stable with ~2.4× margin**.
  Keep **battery + reservoir low and rear**; cap slide extension. Confirm with CAD masses.

### 13.8 Endgame hang (H11 — decision)
- **Deferred to a v2 stretch,** *but* we **reserve the 8th motor port and add a hook
  boss** to the head so the arm can later hook the Elevation Bar (20 pts) without a
  redesign. Not on the v1 critical path.

### 13.9 Motor & pneumatic budget (final)
| Motor | Use | Cartridge / ratio |
|---|-----|---|
| ×4 | X-drive | 600 RPM, ~1:1 |
| ×2 | belts | 600 RPM, ~3.75:1 up |
| ×1 | arm pivot | ~7:1 down |
| (spare) | reserved (hang / assist) | — |

Pneumatics: 1 reservoir, 2 cylinders (slide, latch), 2 solenoids.

**All eleven holes H1–H11 now have a written resolution.** Remaining before CAD:
one adversarial critique pass to catch anything missed (§11 says "iterate to no
holes"), plus confirming the five flagged rule numbers (H9) against the manual PDF.

---

## 15. v1.0 — post-critique resolved design (supersedes §13)

Every §14 finding folded in. Launch-independent holes are closed with corrected
numbers; the two things that genuinely need a bench prototype are called out (§15.9)
rather than fake-closed. **Working launch baseline = flywheel-fed-by-belt** (my
recommendation; reversible — only §15.4 changes if we go catapult).

### 15.0 What survived, what changed
- **Belt keeps 3 of its 4 jobs — intake / hold / push / ball-control — unchanged.**
  It is no longer the launcher (both red-teams: wrong tool for a rigid irregular ball).
- **Launch is now a dedicated flywheel** the belt feeds. This is the only architectural
  change; everything else is a numbers/geometry fix.

### 15.1 Fold kinematics — fixed topology (closes C-B1/B4)
The rear-pivot + 100 mm slide was impossible. New scheme: **center-top pivot +
telescoping slide.**
- **Pivot at the robot center**, z ≈ 110 mm (top of drive deck), in **dual** bearing
  blocks (no single-shear). Driven by the pivot motor.
- **Short arm** (pivot → head carriage) + **slide** provides reach. The head folds into
  the **center-to-rear** deck span (≈190 mm — exactly the head length), mouth rearward,
  for the legal start. Deployed, the arm swings forward-down and the **slide extends** to
  put the mouth at the **front floor** and over the front edge (barrier reach).
- **Swing clearance:** head radius ≈190 mm about a center pivot → peak height ≈300 mm
  < 381 mm cube, and stays within ±190 mm horizontally. **Slide must retract before
  folding** (interlock, C-M12); the swept volume through 0–180° must clear the wheels/
  electronics.
- **Residual (legit CAD item):** exact link lengths + the 0/30/…/180° pose drawings are
  a **CAD swept-volume study** — the topology closes; the millimeters get set on the drawing.

### 15.2 Head — corrected envelope, mass, load path (closes C-B3/M2/M6)
- **Envelope ≈ 190 (L) × 210 (W) × 182 (H) mm**, mass **≈ 2.0 kg** (2× V5 ≈ 0.46 kg alone).
- **Metal structural spine** (VEX C-channel/plate) carries belt tension, the carriage
  joint, and the flywheel/pulley bearing loads; **printed plates become shrouds/guides,
  not primary structure** (obeys §8.1). Pulleys get **VEX/metal hubs or heat-set inserts**
  — no plastic hex bore under launch/intake torque reversal.

### 15.3 Belt intake (role unchanged, re-geared)
- Grips the ≈110 mm body; throat flares to swallow the 157 mm tip; **`BELT_WIDTH` → ~120 mm**
  (≥ body, fixes C-M14). Since the belt no longer launches, gear it for **intake speed
  (~1:1)**, not 3.75:1 — lower stress, no seam-ripple launch dependence (defuses C-M3).
- **1 belt motor** (cross-linked L/R) suffices for intake/hold → frees a port. A throat
  detent/hard stop holds the ball so belts needn't stall-hold (C-m5).

### 15.4 Flywheel launcher (new — closes C2-B1)
- **Dedicated flywheel at the muzzle** with **real metal flywheel mass** (VEX/fabricated) =
  the energy store the belt lacked. Driven by **1 V5 motor geared UP** to a rim speed of
  ~5–7 m/s; **encoder holds RPM**, flywheel inertia carries the shot (no torque-starve).
- **Belt feeds the ball into the flywheel nip; a compression hood** holds it against the
  wheel over a defined arc → more consistent than a single-tangent kick, and sets the
  **launch angle (~40–45°)**.
- **Rate ~1 shot/s** (re-spin); **mid-range** (~4–8 ft, over the 2.9″ barrier, into the
  net) — the far goal (>8 ft) is a stretch, accepted. **Trajectory = launch-from-height,
  and must clear/stay under the midfield Elevation Bar structure** (C2-B2) — a real
  CAD/sim check with field geometry, not the flat-ground formula.

### 15.5 Motor & pneumatic budget (final, ≤8)
| Motor | Use | Cartridge / ratio |
|---|-----|---|
| ×4 | X-drive | 600 RPM ~1:1 |
| ×1 | belt intake (cross-linked) | ~1:1 |
| ×1 | flywheel launch | up to ~5–7 m/s rim |
| ×1 | arm pivot | **100 RPM cartridge** ×~7 → ~14.7 N·m ≫ the ~5.6 N·m hold need (fixes C2-m2) |
| (spare) | 2nd flywheel or 2nd belt | — |
= **7 motors, 1 spare.** Pneumatics: **VEX, ≤2 reservoirs, 100 psi**; **compute the air
budget** — slide gets a mechanical hard-stop; **fold latch is passive over-center** (works
powered-off for inspection). If air budget is tight, motor the slide with the spare port.

### 15.6 Localization + controls (closes C2-M5)
- **2–3 dead-wheel tracking pods** for X/Y odometry (omni encoders slip) + IMU heading →
  field position for auton/skills aiming; a **goal-relative align routine** before launch.
- Ball-present distance sensor → auto-HOLD; launch only when not flooring the drive (peak-
  current, C2-m7). Recoil is a non-issue (~14 N ≪ ~49 N total friction).

### 15.7 Two-robot strategy (closes C2-M4 / R7)
This is the **15″ scorer**; the team's **24″ robot elevates**. Hang deferred here is now
*justified*, not hand-waved. (If we later want this bot to also hang, that's a v2 with the
spare port + a hook — not on the v1 path.)

### 15.8 Margins to re-verify in CAD (with real masses)
Start footprint incl. wheels/fasteners → target frame **≤360 mm (≈0.4″/side margin**, fixes
m1/C-M7); tipping with the ~2 kg head deployed (battery + reservoir low & rear); front-wheel-
gap clearance for the ~210 mm head mid-fold (C-M5).

### 15.9 The two things a prototype must close *before/at* CAD (honest)
Both red-teams agree these can't be closed on paper:
1. **Belt capture of the real rigid tri-ball** — does the throat actually orient/admit a
   157 mm irregular ball without jamming? Bench-test with the real (or printed) ball.
2. **Flywheel launch consistency** with the real ball — measure exit-speed/angle scatter.
→ Recommend a quick physical bench test (or a printed-ball proxy) to de-risk before
committing full CAD; or proceed to CAD with the compression-hood + detent mitigations
designed in and validate on the first print.

---

## 14. Critique round 1 — mechanical red-team (REOPENS "closed" holes)

An adversarial mechanical review re-did the §13 arithmetic and found several
closures don't hold. §13's "all holes closed" is **retracted** pending redesign.

**Blockers**
- **C-B1 Fold kinematics don't close.** Rear pivot + 100 mm slide can't reach the
  front floor *and* fold in-cube: pivot→mouth ≈ 518 mm horizontal, arm ≈ 430–530 mm;
  folding it rearward busts the 381 mm cube by ~250 mm or points it up. → **reopen H1/H6;**
  must publish real pivot (x,z), link lengths, slide stroke, and draw 0–180° poses.
  Likely needs a *central* pivot, longer slide, or a 2nd link.
- **C-B2 Rigid 3-lobe ball breaks belt-launch repeatability.** Belt-speed=exit-speed
  is sphere logic; lobe-apex contact → variable effective radius → non-repeatable
  speed/spin; 157 mm tip won't enter a 100 mm gap (jam risk); TPU must deform ~5 mm
  (> belt thickness). → **architecture question:** prototype on the real ball, or split
  intake (compliant flex-wheel) from launch (flywheel/catapult).
- **C-B3 Head undersized.** Real envelope ≈ **190×210×182 mm** (tip-clearance 170 +2 decks
  = 182; belt+pulley flanges → ~210 wide), not 180×165×150. Every downstream packaging
  number inherits this. → **reopen H1.**
- **C-B4 Rear floor intake can't be both in-cube and reach the floor.** Latched folded
  pose can't put the mouth at the rear floor without ~120 mm rear overhang (busts cube).
  → decide: rear intake is a post-start *deploy* (counts vs expansion cap), or drop it.

**Major**
- **C-M1** 90 mm `BARREL_LEN` < ball → no real acceleration distance (H1 fix broke H8).
- **C-M2** Printed PETG decks + plastic-hex pulleys are in the launch/cantilever load
  path — violates §8.1/M3. Need a metal structural spine + metal-hub pulleys.
- **C-M3** Printed TPU belt @2250 RPM: seam speed-ripple + fatigue = worst launch
  consistency, and R5 forces it. Consider **VEX flex wheels / tank tread** (VEX = legal)
  instead of a belt.
- **C-M4** Single linear slide = compliant cantilever holding ~2 kg → aim sag/creep.
  Need dual rails or a trussed pivot-only arm + a hard stop at the launch angle.
- **C-M5** Head (~210 wide) may not clear the gap between front drive modules mid-fold.
- **C-M6** Head mass ~1.8–2.0 kg (2× V5 = 460 g alone) → pivot hold ≈ 4.9 N·m, tipping
  ~1.8× not 2.4×.
- **C-M7** Cube margin ~0.25″/side excludes omni wheels + fasteners → may exceed 15″.

**Minor:** deployed pose needs a mechanical hard-stop not motor-hold; start latch must
be passive (inspection is powered-off); dynamic tipping unanalyzed; hood-vs-tilt launch
angle contradiction; double-articulation cabling fatigue; slide-retract-before-fold
interlock; deployed 20.5″ rides on the unverified 24″ cap; belt width 90 < body 110.

**Top 3 to fix:** (1) close fold kinematics with real geometry; (2) prototype belt grip
on the real rigid tri-ball before CAD — seriously weigh flex-wheel-intake + flywheel;
(3) reopen H1 with correct head dims + mass + wheel clearance.

### Critique round 2 — rules / controls / launch-physics red-team

**Blockers**
- **C2-B1 No energy store for launch.** 2× V5 @600 RPM geared 3.75:1 up → ~0.19 N·m at
  the pair of 50 mm pulleys, but the shot needs ~0.29 N·m — **motor stall torque is below
  the shot demand.** The energy must come from flywheel inertia the doc never sized;
  ~2 kg flywheel needed for <10% droop (impossible on a 15″ bot), ~0.4 kg → ~30% speed
  droop → range scatter; re-spin ≈ 0.7–1 s → ~1 shot/s. **The belt cannot be a
  repeatable launcher without becoming a flywheel shooter with real (metal) flywheel mass.**
- **C2-B2 Trajectory used flat-ground physics + ignored the field.** `R=v²sin2θ/g` assumes
  equal launch/land height; real shot is launch-from-height into a raised net. At 45°,
  5 m/s → **apex ≈ 24″** — and midfield has the **Elevation Bar structure** ("Over
  **Under**"); the arc must clear/stay under it. Belt-surface 5.9 vs range-calc 3.5–4.9 m/s
  implies unstated 15–40% slip. **Far goal (>8 ft) is unreachable** at this speed →
  mid-range only. Redo trajectory from height into real goal geometry + bar no-fly zone.

**Major**
- **C2-M1** Irregular ball → variable grip radius/release → exit **speed *and* angle**
  scatter at constant RPM; encoder loop can't fix geometry. (Confirms C-B2.)
- **C2-M2/M3 Rules re-framed** (now in R2/R4/R5/R7): 15″ expands to 36″; VEX pneumatics
  ≤2 reservoirs; TPU belts legal (fabricated); COTS bearings/slides legal, COTS gears not;
  only V5 motors; two-robot game. Air budget can run dry — compute or motor the slide.
- **C2-M4** Two-robot strategy undocumented → "defer hang" only valid if the 24″ partner
  elevates (now R7).
- **C2-M5** **No localization** → auton/skills aiming unsupported (IMU = heading only,
  omni odometry slips). Add dead-wheel tracking pods or a goal-relative align routine.

**Minor (verified):** start margin 0.25″/side not 0.5″ (m1); **pivot needs the 100 RPM
cartridge** — deployed r≈0.35 m, m≈1.6 kg → ~5.6 N·m, a 600-RPM×7 gives only ~2.45 N·m
(m2); head mass 1.8–2.2 kg (m3); TPU-belt durability (m4); ports/battery **fine** (m7);
recoil conclusion holds, number was loose (m6). **R3 "≤8 motors" confirmed correct.**

### Synthesis (the decision this forces)
Both red-teams independently conclude: **the belt is an excellent intake / hold / push /
ball-control mechanism but a poor *precision launcher* for a rigid irregular tri-ball.**
The elegant "one mechanism does all four" has to bend at LAUNCH. Everything else is a
fixable numbers/geometry problem (redo the fold kinematics with real link lengths; recompute
the head envelope ≈190×210×182 mm / ~2 kg; add a metal structural spine + VEX-hub pulleys;
add tracking wheels; assign hang to the 24″ partner). **The one fork that needs the user:
how to launch** — see the recommendation in the reply. Once that's set, the fold geometry +
numbers get redone into an airtight v1.0, *then* CAD.

## 16. Gate-driven refinement (v1.1) — verify, don't assert

The CAD was put under 8 automated verification gates (`cad/gates.py`: pairwise
interference, anisotropic ball-path sweep, mount/fastener contact + real
grid-hole membership, fit bands, printed-wall minimums, arm motion sweep,
stow-in-cube). **Baseline: 15 pass / 24 FAIL. Final: 29 pass / 0 FAIL** —
regression-run after every change (`docs/gates_baseline.txt` → `docs/gates_after.txt`).

**Geometry fixed (all verified by re-run, numbers in the logs):**
- **Throat lip rebuilt** — the old part had full-ring slivers from undersized cut
  boxes and side-plate-era flanges burying 518 mm³ into the decks and clipping
  pulleys/belts. Now: grid-bolted top plate + edge wall + flare with **0.00 mm
  aperture intrusion**; all clashes → 0.
- **Bottom lip DELETED, plow re-designed as the bottom ramp** — mount plate on
  the bottom deck's inner face (45° chamfered edge: ball rolls a ramp, not a
  4 mm step), raked blade to the floor. One part = bottom guide + push blade.
- **Rigid-ball squeeze corrected** — `BALL_COMPRESSION 6→4`, `BELT_THK 4→6`
  (constraint: compression ≤ belt−1). Rigid drum now clears the ball body by
  **2.0 mm/side** (was −2: metal-on-ball interference).
- **Pulley** — drum +5 mm (belt axial float 5.0 mm, was 0 = binding), flanges
  moved **outboard of the ball's z-reach** (38 mm margin), lightening windows
  re-sized (window-to-bore wall 1.97→2.52 mm).
- **Motor plates** — seated on the deck (was floating 10 mm), and the second
  plate added; lip/plow bolt holes verified to land on **real** deck grid holes.

**Layout corrected (robot/arm.py is now the single kinematic source):**
- The head (~227 mm wide) is WIDER than the wheel gap (~196 mm) → it can never
  pass between wheels; every swing must clear them vertically. Pivot moved to
  (y=155, z=221), carriage at the head's rear face.
- **Slide REMOVED** (decision, rationale recorded): a straight arm from a high
  pivot provably cannot reach the REAR floor over the rear wheels (head bottom
  ≥ 92 mm at y=−136 forces pitch ≥ −0.7°, i.e. horizontal). Rear floor intake =
  **yaw the holonomic base 180°** (~0.3 s); the stow pose still works the rear
  directly (mouth rearward at ~200 mm: launch / hold / feed). Frees a pneumatic
  circuit, stiffens the arm (red-team C-M4), and front floor intake is reached
  by the pivot alone (mouth at 80 mm = ball centre height at φ=−25°).
- Gates: head-wheel clearance 0.0 → **13.3 mm**; stow-in-cube (NEW gate G8 — the
  old stow pose silently poked the flywheel out of the cube): worst margin **21 mm**.

**Carve-outs / still-open (documented, not hidden):**
1. Bench items unchanged (§15.9): tip-orientation capture at the throat, and
   launch scatter — cannot be closed on paper.
2. TPU belt loop seam durability at speed — bench test.
3. Lip flare overhang needs supports or a split print.
4. G7 (13.3 mm) and G8 (21 mm) margins are adequate but not generous — re-verify
   when real arm-link/carriage CAD replaces the layout primitives.
5. Front-deploy tipping ≈1.5–2× static margin by estimate — verify with CAD
   masses; keep battery/reservoir low and rear.
6. `HEAD_ALONG = 333 mm` includes a ±20 mm flywheel-protrusion estimate — pin it
   down when the launcher hood CAD is integrated into the head assembly.

## 17. Critique round 3 — hard DFM + power/systems red-teams (v1.4 input)

Two independent adversarial reviews (full findings in the v1.4 commit message
and fix log below). The 50/50 gate pass was real but NARROW: gates verified
static geometry, not mechanism logic, fasteners, print orientation, power, or
service access. Headline findings:

**Blockers**
- R3-1 Motors geared to the TENSION-SLOT shafts: tensioning breaks the 1.5"
  gear mesh; the drive shaft's bottom bearing floats in a slot.
- R3-2 Closed-loop TPU belt: unprintable in any good orientation (110 mm TPU
  bridge or a 120 mm stacked Z-seam through the nip) AND unserviceable (no
  axial path over deck-captured pulleys -- a belt swap was a pit teardown).
- R3-3 No belt cross-link: BOM said 1 motor "cross-linked", CAD had 2 plates
  and no linking transmission.
- R3-4 Head decks joined ONLY by two 4 mm printed tabs at the rear; the BOM's
  "metal spine" didn't exist; the launch nip pries the unsupported muzzle.
- R3-5 fly_mount nuts land inside the plow plate footprint (cannot assemble).
- R3-6 STOW "rear launch" fires 40 deg DOWNWARD (inverted nip) with ~1 mm
  engagement -- the rear-launch claim was geometrically false.
- R3-7 Drive gearing overspeed: X-drive sqrt(2) forgotten -> effective 12 ft/s
  on 9.8 kg = 24 N push (0.25 g), 3.6x under traction, near-stall thermal
  death; FLY_RPM=3000 was the motor's no-load asymptote; G11 modelled a launch
  pose that doesn't exist (real FRONT exit = 18 deg).

**Major clusters:** ghost parts (flywheel motor mount, hard-stop, latch,
sensor mounts, tracking pods); no power budget (~17 A worst vs ~20 A); intake
cartridge unspecified + no jam handling; pivot sized on stale 1.6 kg head
(real 3.7 kg); set screws in printed bosses; printed hex bores vs BOM's
metal-hub promise; no drum crown (belt parks on a flange); no grip backing
behind the belt runs; bearing flats un-mountable anywhere (no hole pairs);
fastener stacks eat the 9 mm tip margin; zombie pneumatics subsystem; cable
routing over the 202 deg fold undesigned; deck notch open edges in the ball
path; 1.0 mm running clearances.

## 18. Round-3 fix log (v1.4) + tracked items

**Implemented and gate-verified (60 pass / 0 fail):** all four deck bores FIXED
(tension via lace length — R3-1); belt re-designed as LACED TPU STRIPS (R3-2/C1);
2 belt motors replace the phantom cross-link (R3-3; robot = 8/8 motors); 4 muzzle
standoffs close the nip pry path (R3-4); fly-mount bolts moved clear of the plow
(R3-5); STOW rear-launch claim retracted — rear = HOLD/FEED, launches front-side
(R3-6, poses + captions + BOM corrected); drive re-geared 36:60 → 7.2 ft/s,
40 N push, 3.8 m/s² (G14); FLY_RPM → 2700 plateau, 500 g disc, G11 evaluates the
REAL pose set (LAUNCH φ=0: 3.15 m range; FRONT: 2.20 m flat shot); crowned drums
(D5); set screws deleted → shaft collars (D1); bearing-flat hole pairs at every
bore (C4); blade 6 mm + filleted slot (D4); lip plate covers the notch ceiling
(E1); pneumatics deleted → 700 g steel counterweight (F15); power budget gated
15.5 A (G13); floor-dig gated (G12); pivot re-sized against the 4.1 kg head (F7).

**TRACKED (named, solutioned, not yet modeled):** flywheel-motor mount plate;
deployed hard-stop (tab on pivot_block + pad on arm_hub) and passive over-center
latch + release; heat-set inserts at the hub/deck joints (C2) and lip fastener
flip (C3); grip-backing platen rails behind the belt inner runs (D6); mouth
corner fairings (E2); cable drum + clamp bosses on the hub (F13); distance-sensor
pocket, radio mast, 2 tracking pods (F14); metal arm-hub fallback (D3); wider
fly-mount stance housing wheel+disc between bearings with ball bearings (D7);
assembly-order doc + spares kit (F6). Bench items unchanged: throat capture,
launch k-factor, TPU lace fatigue.

## 12. Change log
- **v1.5 — BUILD-COMPLETE.** All tracked parts modeled: fly_drive_plate,
  hard-stop pin+horn (in hub/block), stow_cradle ×2, platen_rail ×2,
  sensor_mount, tracking_pod ×2, mass_disc + counterweight (fabricated STEPs),
  hub cable boss. Launcher packaging re-solved when gates caught disc clashes:
  1" flex wheel + O72×16 disc inside a widened deck notch, 2 mm below the wheel
  surface. 16 parts, 26-solid assembly, **77 pass / 0 fail**, docs/ASSEMBLY.md
  build guide added. Remaining: bench items + firmware (listed in ASSEMBLY.md).
- **v1.4** — round-3 hard critique (§17) systematically fixed: 21-part assembly,
  8 motors, re-geared drive, laced belts, fixed bores, standoffs, honest rear-work
  claim, pose-true trajectory gate, power/floor/drive gates. 60 pass / 0 fail.
- **v1.3** — flag-closure + launcher integration, all gate-driven (50 pass/0 fail):
  lip gets integral ribs (support-free print) + the launcher HOOD TONGUE; deck/
  plow slotted; **under-mouth reversible flywheel** (3" flex wheel + mass disc,
  `fly_mount` ×2) — intake-assist / retain / launch with NO extra DOF; new gates
  **G10** (mass 9.8 kg est., tip margin 24 mm) and **G11** (trajectory: 6.0 m/s,
  barrier +727 mm, max range 3.83 m, apex 0.96 m — verify vs bar height); head
  envelope now exact (no launcher length estimate); hub print orientation
  corrected (web-flat = no supports). G7 18.5 mm / G8 11 mm margins.
- **v1.2** — real arm-link CAD: `arm_hub` ×2 (hex-keyed web + boss, bolts to both
  decks) and `pivot_block` ×2 (chassis-side bearings), new gate **G9** (6 checks).
  G9 caught a phantom half-pitch bolt column → deck widened so the REAL 114.3 mm
  grid column exists; motor plates slimmed to ±20; pivot z 221→223 for sweep
  clearance. Full suite **41 pass / 0 FAIL** (was 39/2 mid-loop).
- **v1.1** — gate-driven refinement (§16): 8 automated gates, baseline 15/24-fail
  → final 29/0. Lip rebuilt, plow=ramp (bottom lip deleted), rigid-ball squeeze
  corrected, pulley/flange/motor-plate fixes, pivot re-solved, slide removed
  (rear-floor proof), stow-in-cube now gated.

## 12. Change log
- **v1.0** — §15 resolves the post-critique design. Launch → dedicated **flywheel** fed
  by the belt (belt keeps intake/hold/push). Fold fixed to a **center pivot + slide**
  (topology closes; exact link lengths = a CAD swept-volume study). Head corrected
  (≈190×210×182 mm, ~2 kg, metal spine). 7 motors (belt cross-linked, pivot on 100 RPM),
  ≤2 VEX reservoirs, tracking-wheel odometry, hang → 24″ partner. Two bench-prototype
  items (§15.9) flagged as the only things that can't close on paper. Ready for CAD after
  those two are de-risked.
- **v0.4** — two adversarial red-teams (§14) retracted §13's "all closed." Belt is a
  poor precision launcher for the rigid tri-ball (no energy store, orientation scatter);
  fold kinematics don't close as written; head under-sized. Rules re-cited to the VEX U
  appendix (15″→36″ expansion, VEX pneumatics ≤2 reservoirs, TPU legal, VEX gears, two-
  robot game). Blocking decision = launch architecture (to user); rest is a numbers/geometry
  redo → then v1.0 → then CAD.
- **v0.3** — §13 resolves all eleven holes with concrete numbers: compact head
  (≈180×165×150 mm), 3.25″ omni X-drive @600 RPM, belts geared 3.75:1 → ~5.9 m/s
  exit (covers 4–8 ft), motor-driven ~180° fold + pneumatic slide/latch, recoil
  ~14 N (base holds), tipping ~2.4× margin, 7 motors, routing over the pivot,
  hang deferred but provisioned. Next: adversarial critique pass, then CAD.
- **v0.2** — integrated VEXU rules research: §2.1 grounded (15″ robot, no motor cap
  → hold ≤8, COTS pneumatics 100 psi, printed/fabricated parts legal but non-VEX
  COTS mechanicals not → TPU belts; field/scoring targets). Corrected the tri-ball
  to ~6.18″ three-lobed / 138 g (H10), which eases packaging (H1). Motor plan
  fixed at 7. Next: work the §11 holes, starting **H1/H10 (size)** and **H8
  (launch numbers)**, iterate to no holes, *then* CAD.
- v0.1 — foundation (rules-independent architecture, kinematics, interactions,
  fastening, BOM skeleton).

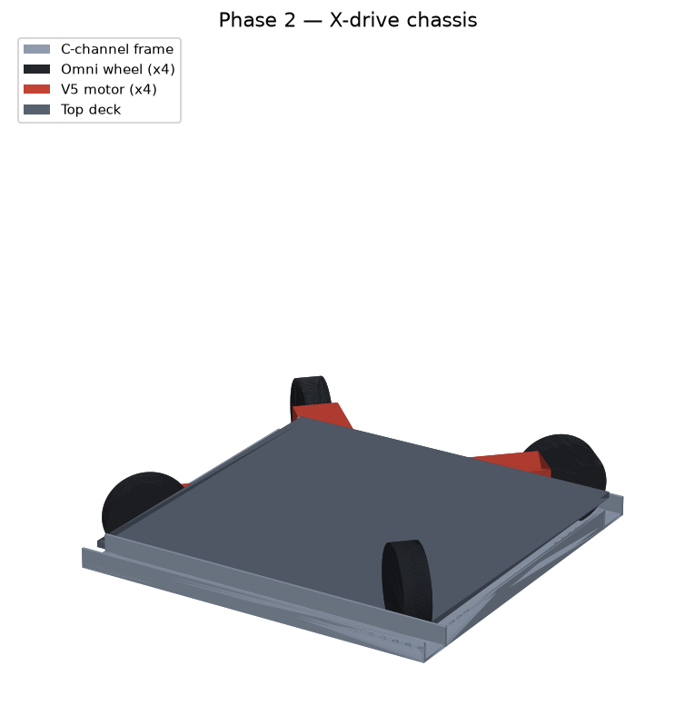
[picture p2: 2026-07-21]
robot/previews/chassis.png

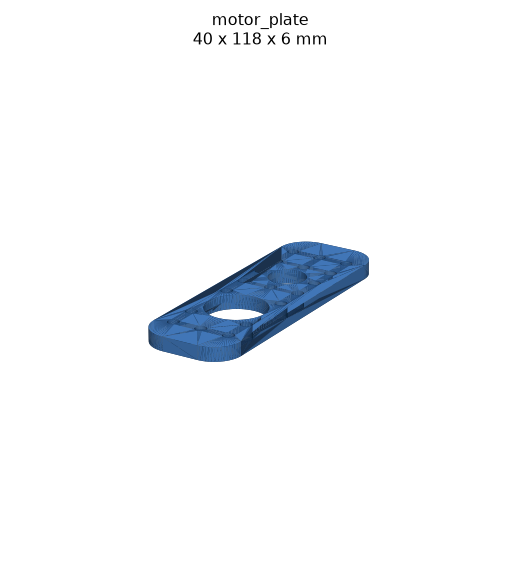
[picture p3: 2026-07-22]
cad/previews/motor_plate.png

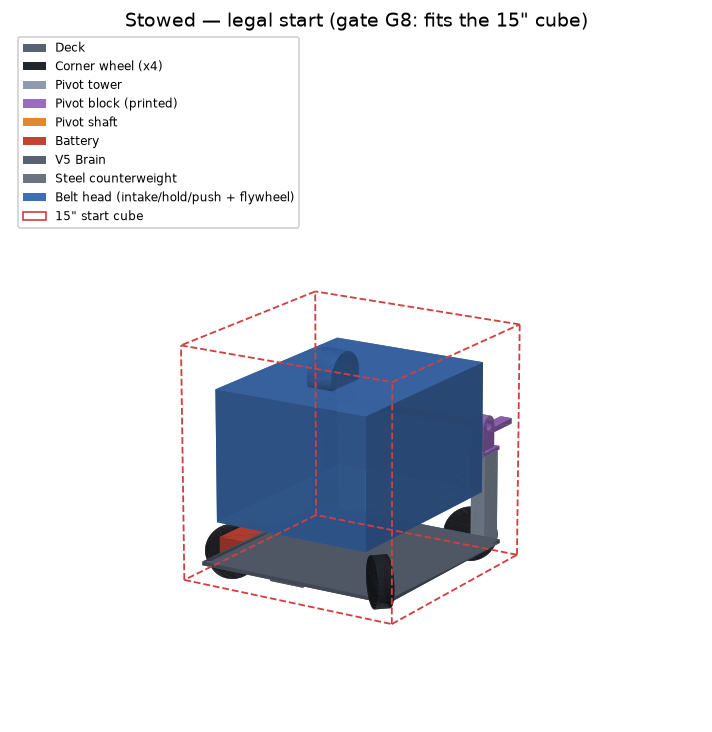
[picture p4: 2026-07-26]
robot/previews/pose_stowed.png

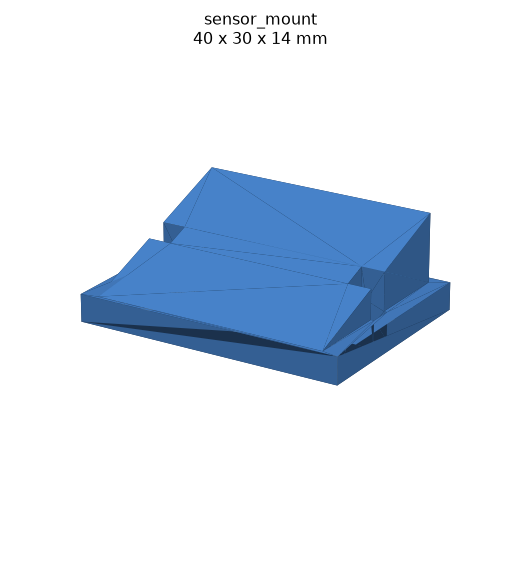
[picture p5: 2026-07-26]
cad/previews/sensor_mount.png

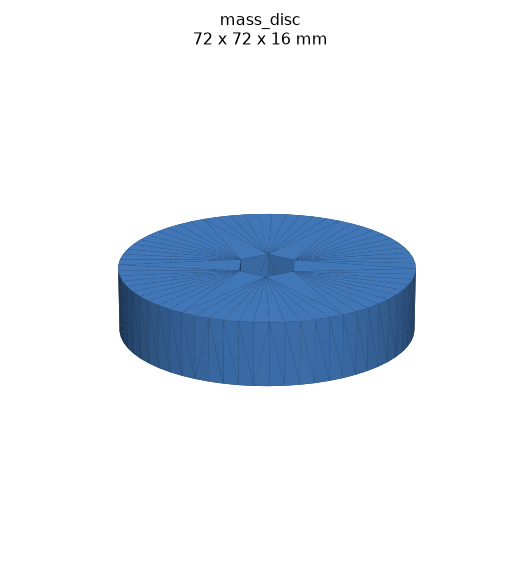
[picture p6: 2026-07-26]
cad/previews/mass_disc.png

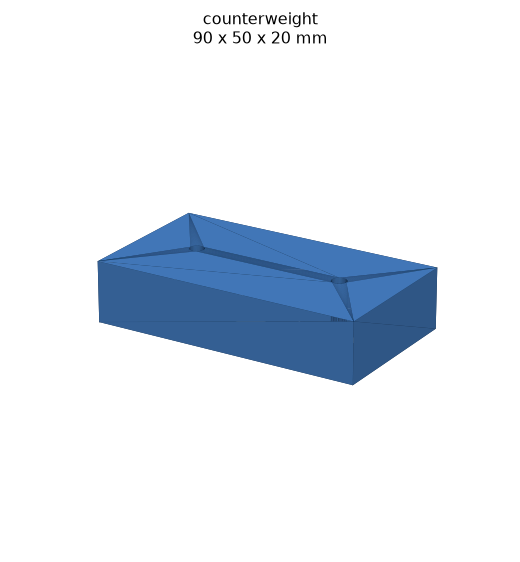
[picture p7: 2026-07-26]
cad/previews/counterweight.png

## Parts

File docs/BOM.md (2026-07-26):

# Bill of Materials — VEXU Over Under 15" scorer

Grouped by subsystem. **Purchased parts are VEX products, pneumatics, or fasteners
only** (VEXU rule VUR — non-VEX COTS mechanicals are illegal); **custom parts are
3D-printed / fabricated** (legal, unlimited). VEX SKUs are given by product name —
**confirm the exact part number in the current VEX catalog before ordering** (SKUs
drift between catalog revisions).

Motor budget: **8 of 8** V5 Smart Motors (at the ≤8 full-current limit exactly).
Pneumatics: **DELETED** (nothing left to actuate — R3 F15); the fold latch is a
passive mechanical over-center (tracked part).

## S1 — Chassis / structure  (purchased: VEX; some custom plate)
| Item | Qty | Purpose | Source |
|---|----:|---|---|
| Aluminum C-channel (1×2×1×25-hole) | ~4 | square frame perimeter | VEX |
| Aluminum plate / gusset stock | a few | corner gussets, decks | VEX |
| Standoffs + couplers | ~8 | separate the drive & arm decks | VEX |
| 8-32 screws (0.375–0.75") + nylock nuts | ~120 | all metal joints on the 0.5" grid | VEX / fastener |
| Heat-set brass inserts (8-32) | ~20 | hub-tab deck joints + service points | fastener |
| `platen_rail` (PETG, 2nd MIRRORED) | 2 | rigid backing behind each belt inner run — grip force reacts into structure (R3 D6) | **printed** |
| `counterweight` steel 90×50×20 (~700 g) | 1 | rear ballast (STEP provided) | **fabricated** |

## S2 — X-drive  (purchased: VEX)
| Item | Qty | Purpose | Source |
|---|----:|---|---|
| 3.25" Omni-Directional Wheel | 4 | holonomic drive @ 45° corners | VEX |
| V5 Smart Motor (11 W) | 4 | drive | VEX |
| ½" high-strength shaft | 4 | wheel axles | VEX |
| High-strength bearing flat | 8 | axle supports | VEX |
| Shaft collar | 8 | axle retention | VEX |
| High-strength spur gears **36T:60T** | 8 | 360 RPM wheel — R3 F1 re-gear (was an effective 12 ft/s / 24 N push) | VEX |

## S3 — Belt intake head  (purchased: VEX shafts/gears/bearings; custom: printed)
| Item | Qty | Purpose | Source |
|---|----:|---|---|
| `belt_pulley` (metal-hub or heat-set) | 4 | belts ride on these | **printed** + VEX hub |
| `drive_belt` **laced TPU strips** (2 per belt) | 4 | printable flat, laced shut in place with a 1.75 mm filament pin — 5-min belt swaps, no seam through the nip (R3 B2/C1) | **printed (TPU)** |
| Lace pins (1.75 mm filament / music wire) | 4 | close the belt loops; length sets tension (bores now all FIXED) | fastener |
| `accel_plate` deck (PETG) | 2 | pulley mounts / ball channel | **printed** |
| `throat_lip` (PETG) | 1 | flared TOP mouth guide, bolts to the deck grid | **printed** |
| `front_plow` (PETG) | 1 | bottom ramp + push blade + bottom mouth guide | **printed** |
| Muzzle standoffs (deck-to-deck) | 4 | close the launch-nip pry path at the mouth corners (R3 A3) | VEX |
| Flat steel strips along deck outer faces | 2 | the "metal spine" — belt-tension load path (hardware, not modeled) | VEX |
| V5 Smart Motor (600 cart, 1.5 A cap) | 2 | one per belt — no cross-link path existed (R3 A2); jam auto-reverse in firmware | VEX |
| ½" hex shaft + bearing flats + shaft collars | 4 sets | pulley shafts (bearing-flat hole pairs now modeled at every bore — R3 C4; collars replace the deleted set screws — R3 D1) | VEX |

## S4 — Fold arm  (purchased: VEX + pneumatics; custom: brackets)
| Item | Qty | Purpose | Source |
|---|----:|---|---|
| ½" high-strength hex pivot shaft | 1 | shoulder axis (hubs keyed to it) | VEX |
| `arm_hub` (PETG, print 2nd MIRRORED) | 2 | keys the head to the pivot shaft; bolts to both decks on the grid | **printed** |
| `pivot_block` (PETG) | 2 | chassis-side bearing blocks on the towers (dual shear, VEX bearing flats) | **printed** |
| V5 Smart Motor + gearbox (~7:1, **100 RPM cart.**) | 1 | fold actuation — re-sized for the REAL 4.1 kg head: hold ≈7 N·m of 14.7 capacity; hard-stop carries the deployed pose | VEX |
| Shaft collars (pivot shaft) | 4 | axial retention of hubs (set screws deleted — R3 D1) | VEX |
| V5 Rotation Sensor (pivot shaft) | 1 | direct angle: motor-encoder-through-7:1 backlash is ±2–3° at the head | VEX |
| `stow_cradle` (PETG) | 2 | passive powered-off stow hold — head rests in foam-padded V-tops (gate G15) | **printed** |
| Hard-stop **pin + horn** | — | integrated INTO arm_hub + pivot_block: deployed pose is a mechanical seat, motor at ~0 A (gate G15) | — |

## S5 — (deleted) Pneumatics
Removed in v1.4 (R3 F15): the slide is gone and the fold latch went passive, so
nothing pneumatic actuates anything. The 700 g steel counterweight (rear, low)
replaces the reservoir's counterbalance role — fabricate from plate stock.

## S6 — Power / electronics / sensing  (purchased: VEX)
| Item | Qty | Purpose | Source |
|---|----:|---|---|
| V5 Robot Brain | 1 | controller (1 per robot) | VEX |
| V5 Robot Battery | 1 | power | VEX |
| V5 Controller + Radio | 1 | driver comms | VEX |
| V5 Inertial Sensor | 1 | field-oriented heading | VEX |
| V5 Distance / Optical Sensor | 1 | ball-present → auto-HOLD | VEX |
| `tracking_pod` (PETG) + 2.75" omni + rotation sensor | 2 | dead-wheel odometry forks (auton aiming) | **printed** + VEX |
| `sensor_mount` (PETG) | 1 | aims the distance sensor into the channel | **printed** |
| V5 Smart Cables | ~10 | motor/sensor wiring | VEX |

## S7 — Launcher  (purchased: VEX; custom: hood)
| Item | Qty | Purpose | Source |
|---|----:|---|---|
| 3" flex wheel (**1" wide**, soft) + ½" hex shaft | 1 | launcher wheel — its compliance IS the nip give | VEX |
| `mass_disc` steel **Ø72 × 16 mm, ~510 g** | 1 | flywheel store beside the wheel INSIDE the deck notch, 2 mm below the wheel surface (gate G15) | **fabricated** (STEP provided) |
| `fly_mount` (PETG, print 2nd MIRRORED) | 2 | hangs the wheel under the mouth; VEX bearing flats | **printed** |
| V5 Smart Motor (600 cart) | 1 | flywheel drive on `fly_drive_plate` | VEX |
| `fly_drive_plate` (PETG) | 1 | motor mount + 12T:60T mesh at exact GEAR_CD, under the bottom deck | **printed** |
| High-strength gears 12T:60T | 2 | 600 cart → ~2700 RPM plateau at the wheel (3000 is the no-load asymptote — R3 F3) | VEX |
| *(hood)* — the `throat_lip` TONGUE is the hood | — | ball squeezed wheel↔tongue; no extra part, no extra DOF | — |

---

**Launcher is reversible**: spinning inward it is an intake-assist roller;
stopped it retains; reversed at speed it fires — **front-side only** (R3-6: at
STOW the head inverts and the nip fires downward; rear work = HOLD/FEED, all
launches happen at the LAUNCH/FRONT poses after a ~0.3 s yaw).

### Motor tally (8 of 8)
4 drive · 2 belt intake · 1 flywheel · 1 arm pivot → **8** (the spare went to
the second belt motor when the cross-link proved to have no path — R3 A2).
Firmware caps per gate G13: drive 4×2.0 A, belts 2×1.5 A, flywheel 2.5 A
(interlocked vs full-throttle drive), pivot 1.0 A → 15.5 A worst case.

### Team note
This is the **15" scorer**; the team's **24" robot handles elevation** (endgame
20/15/10/5). See `docs/DESIGN.md` §15 for the full design rationale.

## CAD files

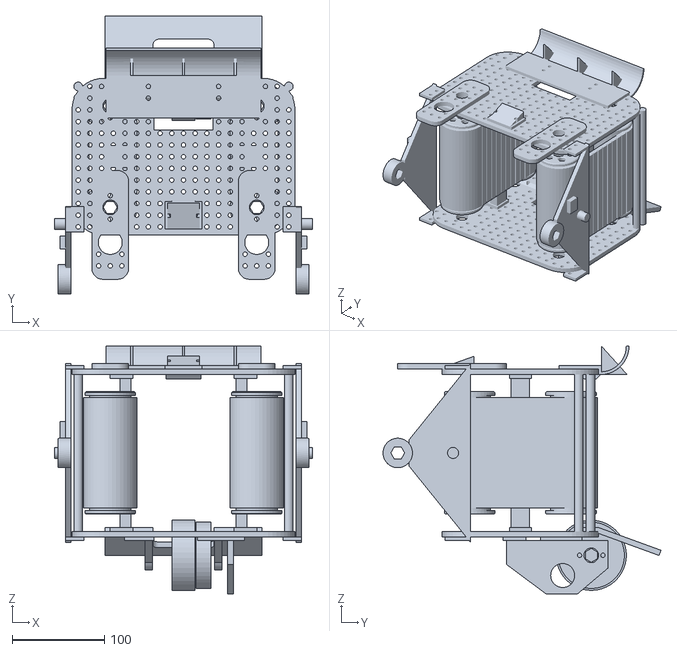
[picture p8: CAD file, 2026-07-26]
cad/stl/_accel_assembly.stl
280.0 x 301.7 x 269.0

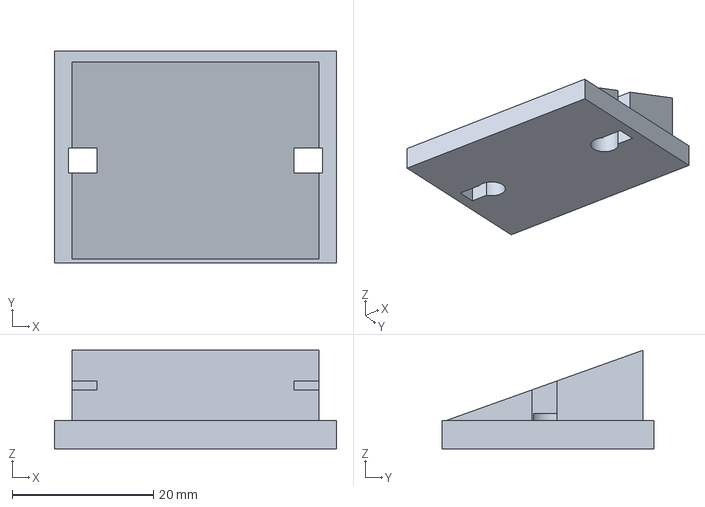
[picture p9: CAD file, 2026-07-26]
cad/step/sensor_mount.step
40.0 x 30.0 x 14.0 mm

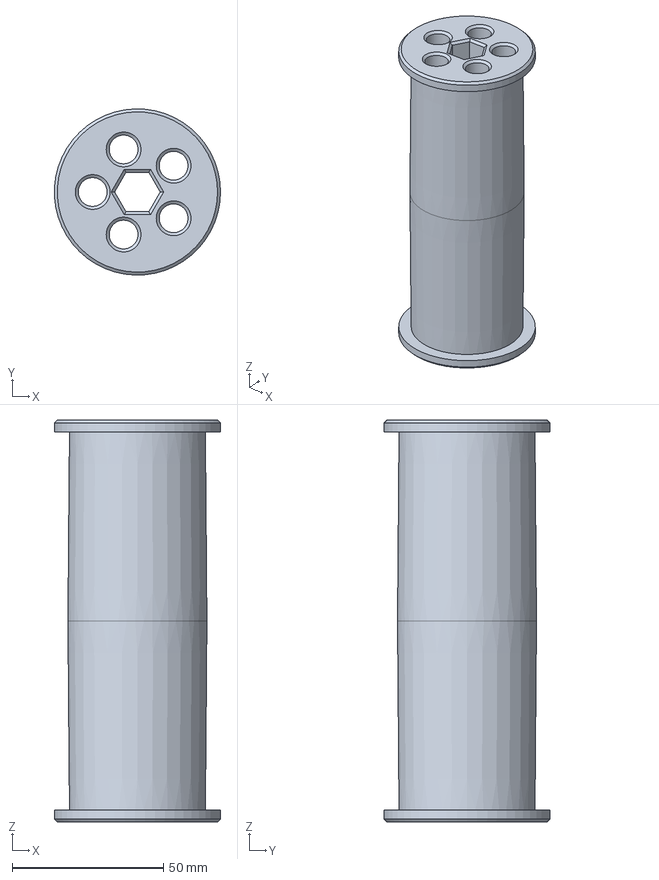
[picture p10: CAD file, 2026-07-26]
cad/step/belt_pulley.step
54.9 x 55.0 x 133.0 mm

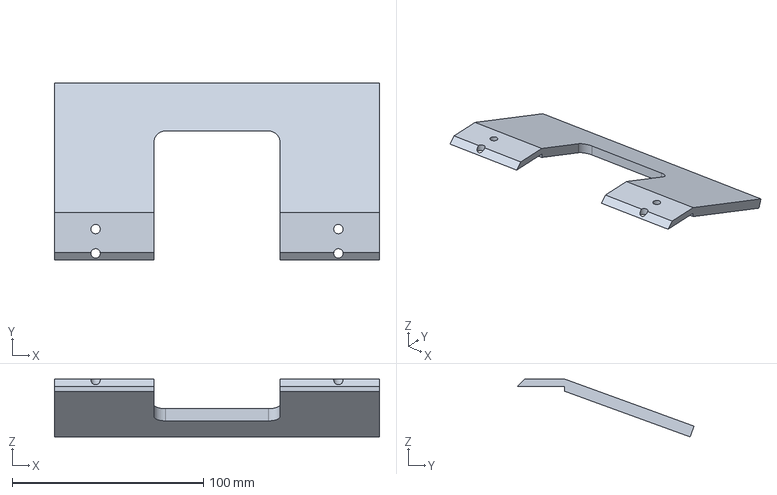
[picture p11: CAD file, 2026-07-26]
cad/step/front_plow.step
170.0 x 92.7 x 30.3 mm

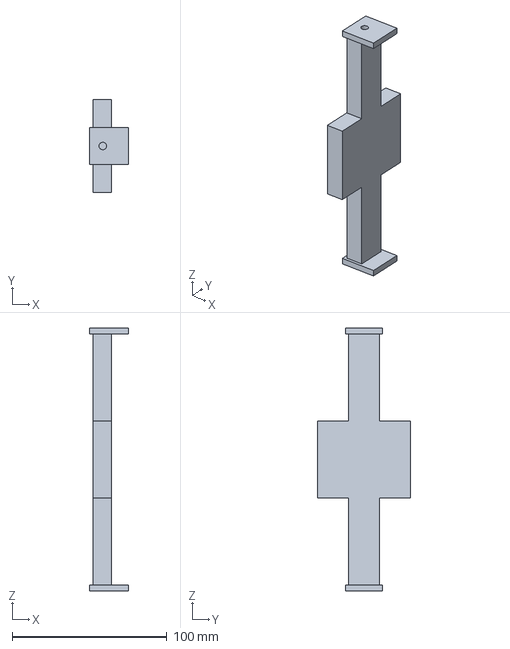
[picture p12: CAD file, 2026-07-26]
cad/step/platen_rail.step
25.0 x 60.0 x 170.0 mm

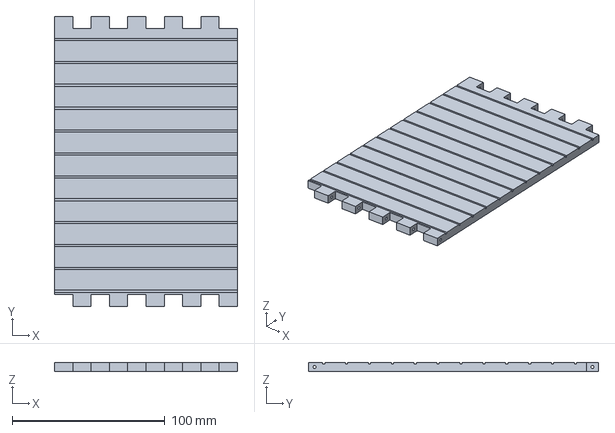
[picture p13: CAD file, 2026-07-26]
cad/step/drive_belt.step
120.0 x 190.1 x 6.00 mm

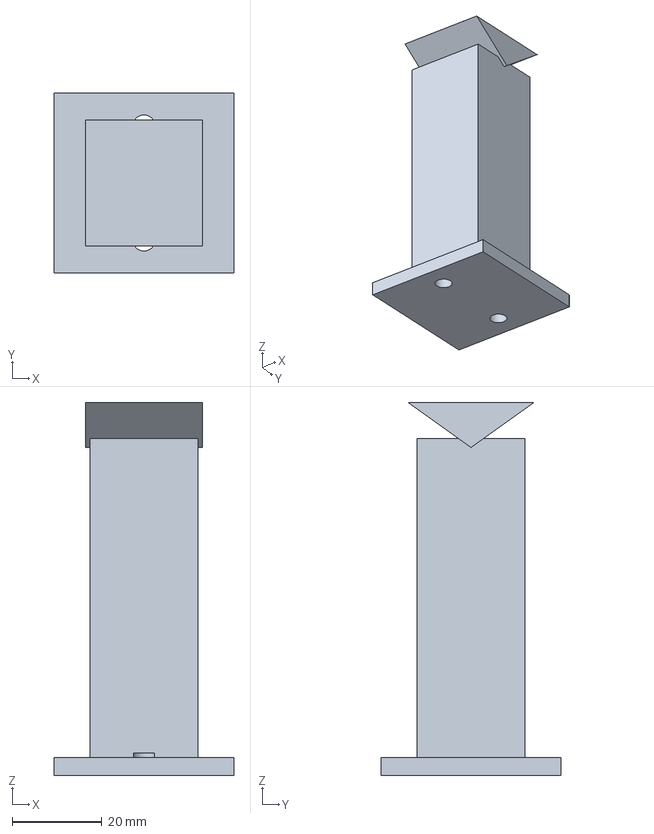
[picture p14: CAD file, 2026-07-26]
cad/step/stow_cradle.step
40.0 x 40.0 x 83.0 mm

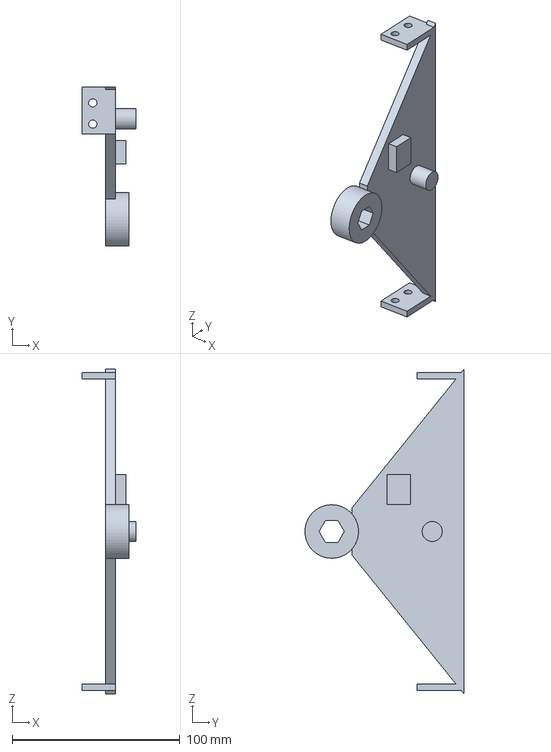
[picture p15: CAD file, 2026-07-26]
cad/step/arm_hub.step
32.0 x 95.0 x 194.0 mm

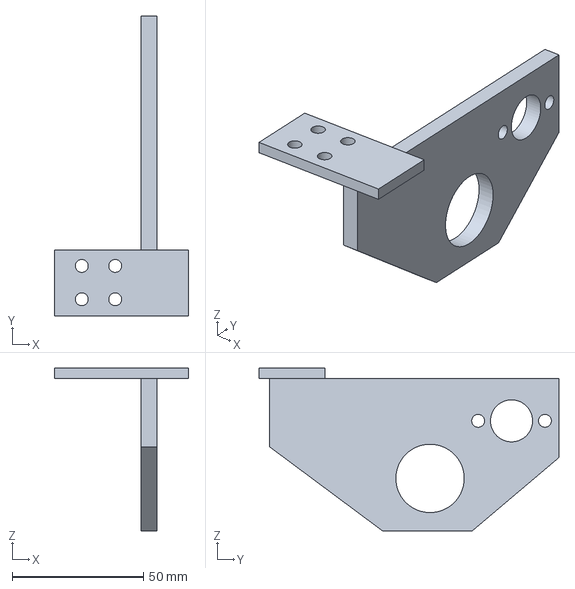
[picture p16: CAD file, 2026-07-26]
cad/step/fly_drive_plate.step
51.0 x 114.0 x 62.0 mm

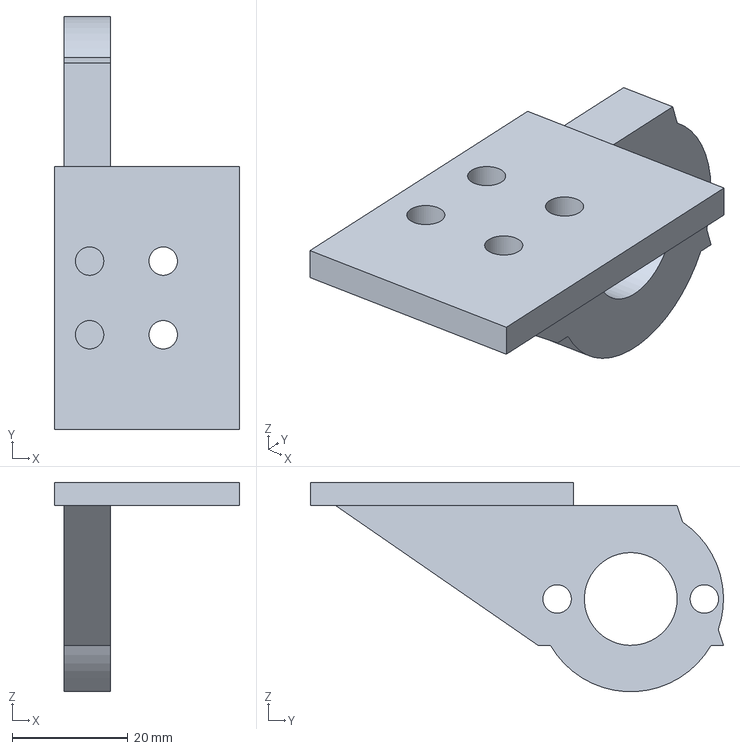
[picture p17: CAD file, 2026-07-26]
cad/step/fly_mount.step
32.0 x 71.2 x 36.1 mm

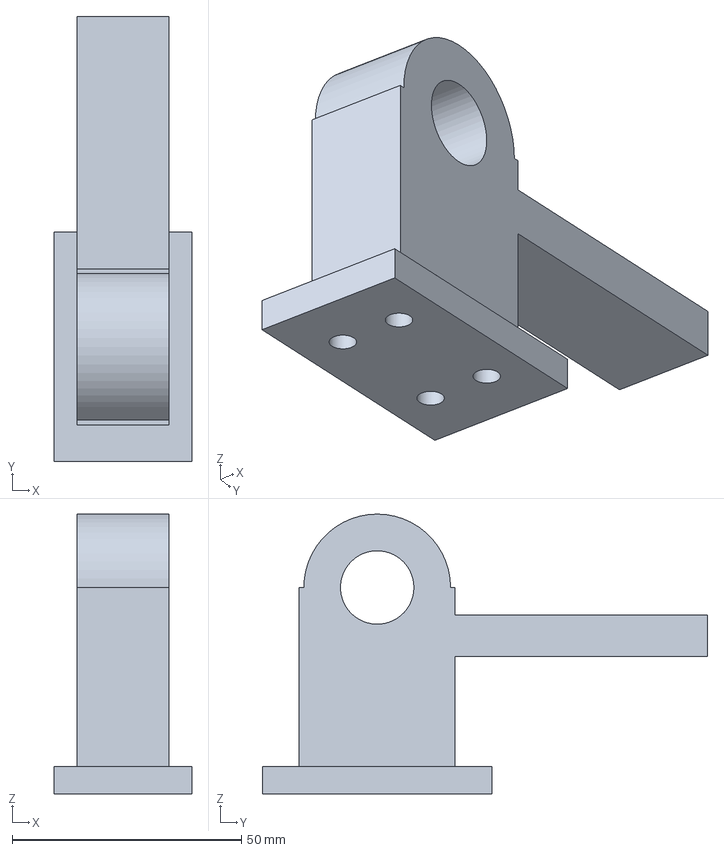
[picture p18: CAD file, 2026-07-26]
cad/step/pivot_block.step
30.0 x 97.0 x 61.0 mm

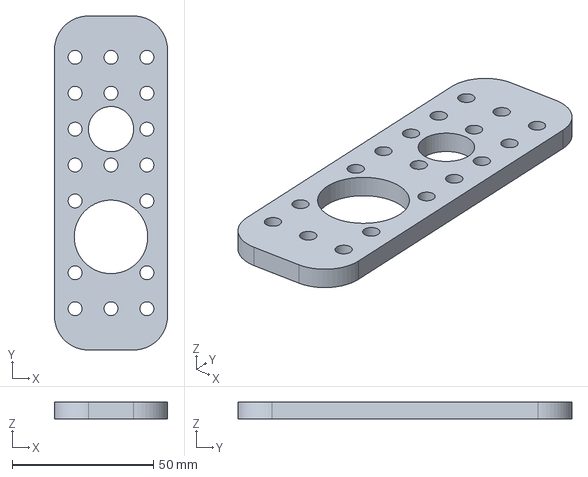
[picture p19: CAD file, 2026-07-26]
cad/step/motor_plate.step
40.0 x 118.1 x 6.00 mm

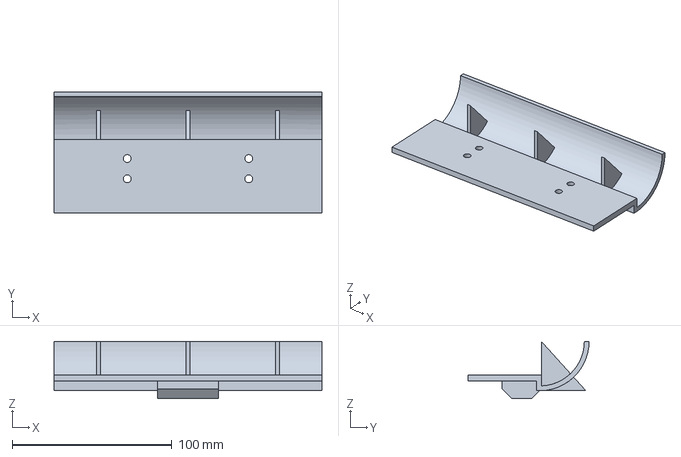
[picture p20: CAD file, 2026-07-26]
cad/step/throat_lip.step
168.0 x 76.0 x 36.0 mm

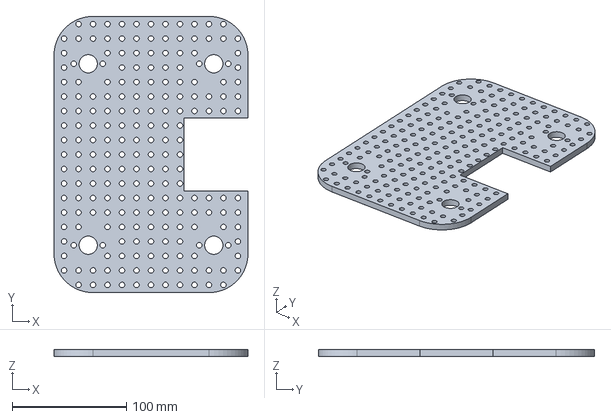
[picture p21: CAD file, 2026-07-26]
cad/step/accel_plate.step
170.0 x 242.0 x 6.00 mm

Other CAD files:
cad/step/counterweight.step
cad/step/tracking_pod.step
cad/step/mass_disc.step
cad/stl/accel_plate.stl
cad/stl/arm_hub.stl
cad/stl/belt_pulley.stl
cad/stl/counterweight.stl
cad/stl/drive_belt.stl
cad/stl/fly_drive_plate.stl
cad/stl/fly_mount.stl
cad/stl/front_plow.stl
cad/stl/mass_disc.stl
cad/stl/motor_plate.stl
cad/stl/pivot_block.stl
cad/stl/platen_rail.stl
cad/stl/sensor_mount.stl
cad/stl/stow_cradle.stl
cad/stl/throat_lip.stl
cad/stl/tracking_pod.stl

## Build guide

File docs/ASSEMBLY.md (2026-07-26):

# Build Guide — VEXU Over Under 15" Scorer

Every custom part has STEP (`cad/step/`) + STL (`cad/stl/`); print counts and
materials are in `docs/BOM.md`. Verify any change with `python -m cad.gates`
(77 checks) before printing. Tools: 3/32" + 5/64" hex drivers, 11/32" nut
driver/wrench, soldering iron (heat-set inserts), lighter (TPU lace ends).

## Print / fabricate first
| Part | Qty | Material / notes |
|---|----:|---|
| accel_plate | 2 | PETG 40%; print rotated ~40° on the bed, raft; check flatness < 0.5 mm |
| belt_pulley | 4 | PETG; bore-up |
| drive_belt strips | 4 (2/belt) + spares | TPU 95A flat; tread up |
| throat_lip | 1 | PETG; plate-down (ribs are the supports) |
| front_plow | 1 | PETG 50%; blade-edge-up with supports (impact part — consider a spare) |
| arm_hub | 2 (2nd MIRRORED) | PETG 50%, 6 walls; web-flat, supports under boss+tabs; metal fallback if tabs flex |
| pivot_block, fly_mount (2nd mirrored), fly_drive_plate, platen_rail (2nd mirrored), sensor_mount, stow_cradle ×2, tracking_pod ×2 | — | PETG; base-down |
| mass_disc Ø72×16 (~510 g), counterweight 90×50×20 (~700 g) | 1 + 1 | FABRICATED steel; deburr, spin-balance the disc |

## Head assembly (on the bench, upside down then flipped)
1. **Bottom deck**: bolt bearing flats over all 4 pulley bores (the ±12.7 mm
   hole pairs); bolt the **plow** plate to the inner face (±63.5 columns,
   countersunk heads) and the two **fly_mounts** + **fly_drive_plate** to the
   outer face (bearing flats on their bores).
2. **Flywheel shaft**: slide in ½" hex carrying **3" flex wheel (1" wide) +
   mass disc** (disc on the +x side, 2 mm clear of everything — gate-verified);
   collars outboard. Add the 60T gear on the motor, 12T on the shaft; bolt the
   flywheel **V5 motor (600)** to the drive plate pilot.
3. **Pulleys + belts**: stand the 4 crowned pulleys on their hex shafts in the
   bottom-deck bores; collar below. Wrap each **belt** (2 laced strips) around
   its pulley pair, lace shut with a filament pin, melt-mushroom the ends.
   **Platen rails** bolt between the decks behind each belt's inner run.
4. **Top deck** on: shafts through the bores (bearing flats outside), 4 muzzle
   **standoffs** at the ±114.3 columns, **throat_lip** on top at the muzzle
   (tongue centred over the wheel), **motor plates + 2 belt motors** (600,
   36T:36T or direct) at the rear, **sensor_mount** behind the lip.
5. **Arm hubs**: bolt tabs to both decks at the ±114.3 rear columns (heat-set
   inserts in the decks recommended); hex-key both hubs to the **pivot shaft**;
   collars at the bosses. Zip the 4 head cables to the hub **cable boss**, leave
   a 160 mm service loop across the pivot.

## Chassis + integration
6. **X-drive**: VEX C-channel square frame (360 mm), 4 corner modules — 3.25"
   omni, 36T:60T gear-down, V5 motor (600) each; wheels at 45°.
7. **Towers**: two C-channel towers at y=155, capped by the **pivot_blocks**
   (bore at z=219 exactly — gate G15); slide the head's pivot shaft through the
   block bearings; collars. The hub **pin** must land on the block **horn** at
   the horizontal (LAUNCH) pose — that's the hard stop.
8. **Pivot motor** (100 RPM cart, ~7:1 to the shaft) on a tower + **rotation
   sensor** on the shaft's free end.
9. **Deck furniture**: battery + brain at y=-120, steel **counterweight** at the
   rear, **stow_cradles** at (±60, -120) with adhesive foam pads — the folded
   head rests on them powered-off (inspection). **Tracking pods** under the
   frame (one X, one Y), rubber-banded down. Radio high on a tower, clear of
   metal.

## Firmware must-haves (gate G13/G14 assumptions)
Current caps: drive 4×2.0 A, belts 2×1.5 A, flywheel 2.5 A, pivot 1.0 A.
Belt jam auto-reverse (250 ms stall → 300 ms reverse). Flywheel recovery
inhibited during >50% drive. Brake-slew limit when the arm is below 30°.
Launch sequence: yaw-align → pivot to hard-stop → spin to commanded RPM →
belts feed. Rear work at STOW is HOLD/FEED only.

## Bench checklist before first match (the paper-unprovables)
Throat capture rate with a real tri-ball (all orientations); launch k-factor
(commanded RPM vs measured exit speed → recalibrate G11); TPU lace fatigue
(500 cycles); pivot backlash at the head; sizing cube WITH cables zip-tied.

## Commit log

2026-07-21 Import VEXU Over Under robot project: belt mechanism + design doc + layout CAD
    - cad/ : the tri-ball belt accelerator (parametric CadQuery -> STEP+STL+preview)
    — the intake/hold/push/launch mechanism, VEX-standard.
    - docs/DESIGN.md : full VEXU Over Under robot design, grounded in the rules and
    iterated through two adversarial red-teams to v1.0. Belt does
    intake/hold/push; launch -> a dedicated flywheel it feeds; fold arm on
    a center pivot + telescoping slide; X-drive; 7 motors; hang to the
    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
    [_accel_assembly.stl, accel_plate.step, accel_plate.stl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]
2026-07-21 Phase 2: parametric X-drive chassis (C-channel frame + corner omni/V5 modules + deck)
2026-07-22 Phase 3: fold arm (pivot blocks + slide) + swept-volume study (wheel clearance)
2026-07-22 Phase 4: re-size belt intake head to the real 6.18in tri-ball (corrected params + regen)
    [_accel_assembly.stl, accel_plate.step, accel_plate.stl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]
2026-07-22 Phase 6: finalized BOM (VEX products + printed parts) + refreshed assembly poses
2026-07-22 Gate-driven CAD refinement: 15 pass/24 FAIL -> 29 pass/0 FAIL
    Verification-first pass over the belt-head CAD + robot layout (cad/gates.py,
    8 gates; logs: docs/gates_baseline.txt -> docs/gates_after.txt).
    Geometry: throat lip rebuilt (grid-bolted plate + edge wall + flare, zero
    aperture intrusion; old part had sliver rings + side-plate-era flanges clashing
    518 mm3 into the decks); bottom lip deleted -- plow re-designed as the bottom
    ramp + push blade (chamfered, no step in the ball path); rigid-ball squeeze
    corrected (compression 4 / belt 6 -> drum clears ball body 2 mm/side, was
    interfering); pulley drum +5 mm with flanges outboard of the ball's reach and
    re-sized windows; motor plates seat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
    [_accel_assembly.stl, accel_plate.step, accel_plate.stl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]
2026-07-22 Real arm-link CAD: arm_hub + pivot_block, gated (41 pass / 0 FAIL)
    Replaces the layout-primitive arm with real printable parts:
    - arm_hub (x2, left mirrored): hex-keyed boss on the pivot axis + web riding
    1 mm outside the deck edge + tabs bolting to BOTH decks -- carries the head's
    moment into the shaft as a rigid triangle. Set-screw phase lock.
    - pivot_block (x2): chassis-side bearing blocks on the towers (VEX bearing
    flats seat over the bore), dual shear; 0.5" grid hold-down.
    New gate G9 (arm integration): hub bolts land on REAL deck grid holes, web/
    motor-plate/block clearances, block-bore-on-axis arithmetic, hex fit. G9
    caught the hub bolt column sitting on a phantom half-pitch gr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
    [_accel_assembly.stl, accel_plate.step, accel_plate.stl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]
2026-07-23 Flag closure + launcher integration, gate-driven (50 pass / 0 FAIL)
    Closes every flagged carve-out with a verified solution, then integrates the
    launcher into the head:
    Flags -> solutions:
    - Lip flare print supports -> INTEGRAL RIBS (support-free, stiffer).
    - Hub "needs supports" -> false: web-flat print is all walls; docstring fixed,
    plus a metal-fabrication fallback note.
    - Head envelope estimates -> exact: the launcher lives UNDER the mouth, so
    HEAD_ALONG carries no flywheel guess; envelope = main box + mouth lobe.
    - Tipping estimate -> new gate G10: mass roll-up from real part volumes +
    hardware table (9.8 kg est.), CoM at FRONT+ball, tip margin 24 mm (battery
    bank moved rearwar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
    [_accel_assembly.stl, accel_plate.step, accel_plate.stl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]
2026-07-23 Add fly_mount to the export list (STEP/STL/preview were missing)
    [fly_mount.step, fly_mount.stl]
2026-07-23 Round-3 hard critique fixed systematically: 60 pass / 0 FAIL (was 50)
    Two adversarial red-teams (DFM/assembly + power/controls) found 30+ holes the
    geometry gates could not see. All blockers + majors fixed and gate-verified:
    MECHANISM LOGIC: all four deck bores FIXED (the motors were geared to the
    sliding tension-slot shafts -- tensioning broke the mesh); belt tension now set
    by LACED-STRIP belt length. Belt redesigned as flat TPU strips laced in place
    with a filament pin: printable (the closed loop was not), no Z-seam through the
    nip, and a 5-minute belt swap instead of a top-deck teardown. Two belt motors
    replace the phantom cross-link (8/8 motors). Four muzzle standoffs close the
    launch-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
    [_accel_assembly.stl, accel_plate.step, accel_plate.stl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]
2026-07-26 Build-complete round: all tracked parts modeled, 77 pass / 0 FAIL
    Models the last ghost parts so every custom component has real STEP/STL:
    fly_drive_plate (flywheel motor + 12:60 mesh at exact CD, verified clear of
    deck/belts/blade/floor-at-FRONT), hard-stop pin (arm_hub) + horn (pivot_block)
    so the deployed pose seats mechanically at 0 A, stow_cradle x2 (passive
    powered-off hold for inspection), platen_rail x2 (grip backing behind the belt
    runs), sensor_mount, tracking_pod x2, and fabricated-steel drawings for the
    mass_disc and rear counterweight. Cable boss added to the hub (fold-crossing
    strain relief).
    Gates caught and drove three real packaging fixes mid-round: the pivot-block
    horn flo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
    [_accel_assembly.stl, accel_plate.step, accel_plate.stl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]
